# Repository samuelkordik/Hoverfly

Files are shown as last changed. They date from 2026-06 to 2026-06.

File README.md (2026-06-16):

# Hoverfly
"Hoverfly" was the nickname given by the RAF to the Sikorsky R-4, the first military helicopter to enter service for Allied forces (during WWII). So it's the name I'm giving to my first 3D printer.

The printer is a Creality Ender 3 Pro with the following modifications/additions:

- SKR Mini E3 V2.0 mainboard
- Dual Z-axis — two steppers + lead screws, parallel-wired to the single Z driver
- Sprite Extruder Pro direct-drive extruder + hotend
- Dual 24 V 5015 blower parts cooling on a printed Taurus V5 duct
- CRTouch probe
- Marlin firmware

This repository is for me to keep track of configuration and firmware files.

## Documentation

- **[Firmware review](docs/firmware-review/index.html)** ([markdown](docs/firmware-review/firmware-review.md)) — prioritized Marlin config recommendations.
- **[Orca Slicer guide](Orca_Slicer/index.html)** ([markdown](Orca_Slicer/orca-slicer-guide.md)) — Elegoo PLA, with Speed and Quality profiles.
- **[Calibration & tuning guide](Calibration_Guide/index.html)** — 9-step ordered tune-up with [STL test models](Calibration_Guide/STL/) and ready-to-run [SD macro files](Calibration_Guide/macros/) (no G-code terminal needed — everything runs via the LCD, Orca's calibration tests, or printing a macro from SD); also a structured [GUIDE.md](Calibration_Guide/GUIDE.md) and a [CLAUDE.md](Calibration_Guide/CLAUDE.md) for working through calibration interactively with Claude.

### How these were built

These guides were produced by a multi-agent research workflow: parallel agents did real web research
(Marlin docs, Ellis' Print Tuning Guide, Teaching Tech, RepRap wiki, and vendor/community sources)
grounded in Hoverfly's actual firmware values, then wrote the guides, the 9-step procedure, and the
calibration test STLs. The raw structured findings behind every recommendation — including seven that
were recovered from the agent transcripts after the run was interrupted partway — are preserved in
[`docs/research/`](docs/research/README.md). The firmware review changes no firmware files; it's advisory,
and motion/temperature numbers should be confirmed against the calibration guide before you commit them.

## Hardware mods (current + planned)

**Current**

- **Dual Z** — two Z steppers + lead screws on the Creality kit's **parallel** Y-splitter, off the single
  Z driver (the board has no spare). Firmware is correctly single-Z. Works as-is; if Z ever lacks torque,
  raise the Z driver current, or switch to a series splitter cable.
  See [firmware review §1](docs/firmware-review/index.html#dualz).
- **Parts cooling** — the stock fan died; replaced with **dual 24 V 5015 blowers** on a printed
  **Taurus V5 duct (PLA)**, spliced to the Sprite Extruder Pro's part-fan connector (driven by the
  mainboard's FAN0). Firmware: add `FAN_KICKSTART_TIME` / `FAN_MIN_PWM` so they start at low PWM.
  See [firmware review: fan wiring](docs/firmware-review/index.html#fans). (The PLA duct sits near the
  hotend — reprint in PETG/ABS if it sags.)

**Planned**

- **12 V buck converter** off the PSU → barrel-jack receiver, to run a 12 V fan that circulates the
  **heated bed's warmth for drying filament**.
- **5 V buck converter** off the PSU → USB-A port, for a **removable** USB LED light bar (kept unwired so
  it can come off for other uses).
- **Klipper migration** — host on a wiped x86 ThinkPad, reflash the SKR Mini E3 V2.0; gains a web G-code
  console (which removes the current no-terminal limitation) and first-class input shaping. Marlin-now is
  the priority. See [firmware review: Future — Klipper](docs/firmware-review/index.html#klipper).

> The buck converters are PSU-side (no firmware impact). Size them to the PSU's spare wattage, fuse each
> output, and use appropriate wire gauge.

## Marlin Configuration Adjustments
Using the "Creality/Ender-3 Pro/BigTreeTech SKR Mini E3 2.0" config example, with the following key changes:

```c
#define DEFAULT_KP 21.73
#define DEFAULT_KI 1.54
#define DEFAULT_KD 76.55

#define DEFAULT_AXIS_STEPS_PER_UNIT { 80, 80, 400, 423 } // E calibrated for the Sprite Extruder Pro
#define EDITABLE_STEPS_PER_UNIT                           // Allow tuning steps/mm from the LCD / via M92

//#define Z_MIN_PROBE_USES_Z_MIN_ENDSTOP_PIN      // Probe is connected to Z-probe slot on board, not Z endstop.
#define USE_PROBE_FOR_Z_HOMING                    // Force use of probe for Z-axis homing
#define BLTOUCH
#define NOZZLE_TO_PROBE_OFFSET {-30, -40, -3.49 } // Experimentally verified.
#define PROBING_MARGIN 50                         // Wanting to stay inside bed cleanly
#define XY_PROBE_FEEDRATE (50*60)                 // Not sure why
#define MULTIPLE_PROBING 2                        // Doing two readings (average of fast + slow) seems like a good idea.
#define Z_PROBE_OFFSET_RANGE_MIN -10
#define Z_PROBE_OFFSET_RANGE_MAX 10
#define X_BED_SIZE 210                            // To ensure probe is able to stay in bed; might adjust in future
#define Y_BED_SIZE 210

#define AUTO_BED_LEVELING_BILINEAR
//#define MESH_BED_LEVELING
#define RESTORE_LEVELING_AFTER_G28
#define PREHEAT_BEFORE_LEVELING                    // Of course, we want this—shouldn't this be the default?

#define Z_SAFE_HOMING
  #define Z_SAFE_HOMING_X_POINT ((X_BED_SIZE - 10) / 2)  // (mm) X point for Z homing
  #define Z_SAFE_HOMING_Y_POINT ((Y_BED_SIZE - 10) / 2) // (mm) Y point for Z homing

#define HOMING_FEEDRATE_MM_M { (50*60), (50*60), (4*60) }
```

And in Configuration_adv.h:

```c
//#define USE_CONTROLLER_FAN                      // Because the controller (mainboard) fan is wired to PWR instead of fan1

#define E0_AUTO_FAN_PIN FAN1_PIN                  // Hot-end fan is wired to FAN1 connector on board
```

## Changes Since Last Documented

These adjustments were made to the Marlin configuration *after* the table above
was first written and were not reflected in it. They are highlighted here so the
delta is easy to track.

### `Configuration.h`

- **Extruder steps/mm: `93` → `423`.** `DEFAULT_AXIS_STEPS_PER_UNIT` was bumped
  from the stock Ender-3 value to calibrate the **E axis** for the Sprite
  Extruder Pro direct drive. The X/Y/Z values (`80, 80, 400`) are unchanged.

  ```c
  -#define DEFAULT_AXIS_STEPS_PER_UNIT   { 80, 80, 400, 93 }
  +#define DEFAULT_AXIS_STEPS_PER_UNIT   { 80, 80, 400, 423 }
  ```

- **Added `EDITABLE_STEPS_PER_UNIT`.** Enables tuning steps/mm at runtime from
  the LCD or via `M92` (and storing it to EEPROM), which makes dialing in the
  new extruder calibration easier.

- **`NUM_M106_FANS` example changed `1` → `2`.** Still commented out, so this is
  a no-op functionally — noted only for completeness.

  ```c
  -//#define NUM_M106_FANS 1
  +//#define NUM_M106_FANS 2
  ```

### `Marlin/src/pins/stm32f1/pins_BTT_SKR_MINI_E3_V2_0.h`

- **Disabled the board-default controller-fan pin.** The `CONTROLLER_FAN_PIN`
  fallback to `FAN1_PIN` was commented out. This complements the disabled
  `USE_CONTROLLER_FAN` in `Configuration_adv.h` and keeps **FAN1** dedicated to
  the hot-end auto-fan (`E0_AUTO_FAN_PIN`), since the mainboard fan is wired to
  PWR rather than a fan header.

  ```c
  -#ifndef CONTROLLER_FAN_PIN
  -  #define CONTROLLER_FAN_PIN            FAN1_PIN
  -#endif
  +// #ifndef CONTROLLER_FAN_PIN
  +//   #define CONTROLLER_FAN_PIN            FAN1_PIN
  +// #endif
  ```

> Note: these changes currently exist as uncommitted edits in the `Firmware`
> submodule (working tree), so they are not yet captured in the submodule's git
> history.

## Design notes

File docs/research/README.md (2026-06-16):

# Recovered research payloads

Raw structured output from the multi-agent research workflow that produced the
[firmware review](../firmware-review/index.html), [Orca Slicer guide](../../Orca_Slicer/index.html),
and [calibration guide](../../Calibration_Guide/index.html). Kept here as the source data behind those
guides — the guides are the curated output; these are the unedited findings.

## Why these exist

The workflow ran **10 research agents** (each doing real WebSearch/WebFetch across Marlin docs, Ellis'
Print Tuning Guide, Teaching Tech, RepRap wiki, and vendor/community sources) before the build phase.
The session hit its limit mid-run: only **3** research results were captured and fed the build agents;
the other **7** finished their work but their results were lost when the orchestrator stopped. All 10
were later **recovered from the agent transcripts** and the genuinely-new findings folded back into the
guides (see [the firmware review changelog of findings](../firmware-review/firmware-review.md)).

| File | Topic | Recs | Into build? |
|---|---|-----:|:---:|
| [`firmware.json`](firmware.json) | Prioritized Marlin firmware review | 12 | recovered |
| [`orca.json`](orca.json) | Orca setup, Elegoo PLA, Speed + Quality profiles | 16 | recovered |
| [`cal-esteps-flow.json`](cal-esteps-flow.json) | E-steps / extrusion-multiplier (flow) | 6 | ✅ captured |
| [`cal-pid.json`](cal-pid.json) | Hotend PID autotune (M303) | summary | recovered |
| [`cal-zoffset-firstlayer.json`](cal-zoffset-firstlayer.json) | CRTouch Z-offset / first layer | summary | recovered |
| [`cal-temp-tower.json`](cal-temp-tower.json) | Temperature tower (Elegoo PLA) | 6 | ✅ captured |
| [`cal-retraction-pa.json`](cal-retraction-pa.json) | Retraction + pressure/linear advance | 7 | recovered |
| [`cal-speed-accel.json`](cal-speed-accel.json) | Max speed / acceleration / junction deviation | 7 | ✅ captured |
| [`cal-input-shaping.json`](cal-input-shaping.json) | Ringing / Input Shaping (M593) | 6 | recovered |
| [`cal-bed-mesh.json`](cal-bed-mesh.json) | Bed leveling / mesh (G29) | 6 | recovered |

## Schema

Each file is one research topic:

```jsonc
{
  "topic": "…",
  "summary": "concise overview of findings",
  "recommendations": [
    {
      "title": "…",
      "priority": "High | Medium | Low",
      "currentValue": "current config/slicer value or n/a",
      "recommendedValue": "…",
      "rationale": "why",
      "howToApply": "exact #define / M-code / slicer setting",
      "sources": ["https://…"]
    }
  ],
  "procedure": "step-by-step test + pass/fail (calibration topics only)",
  "imageNeeds": ["…"],
  "stlModel": "test model used, or empty"
}
```

> These are **point-in-time** web-research artifacts (gathered mid-2026). Treat the guides as the
> reviewed, deduplicated version; consult these for the full rationale and source URLs behind a
> recommendation. `cal-pid` and `cal-zoffset-firstlayer` are summary-only (no structured
> recommendations array) — that's how they were returned.

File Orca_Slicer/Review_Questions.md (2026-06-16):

# Orca Slicer Guide — Review Questions & Notes

My read-through of [`orca-slicer-guide.md`](orca-slicer-guide.md) / [`index.html`](index.html) before I
build the printer profile. Comfortable with the config logic; new to slicer conventions.

## Questions

1. **Bed 210 vs the 220 plate — RESOLVED: keep 210.** The guide sets the Orca bed to **210 × 210** to
   match firmware (`X/Y_BED_SIZE 210`), accepting a ~10 mm dead border on the physical 220 plate. The
   `Ender 3 S1 Pro buildplate 220x220.stl` and `Grid Texture 220x220.png` in the repo root are **not**
   the target — treat them as unused/cosmetic, don't wire them into the Orca bed model (a 220 texture
   under a 210 bed shape would mismatch). No guide change needed. *(Decision confirmed 2026-06-16.)*

2. **Does Orca's jerk setting do anything here?** §2 lists "Jerk X/Y ~8 (advisory)" and notes classic
   jerk is **off** (firmware uses Junction Deviation 0.08). If firmware ignores jerk in favor of JD,
   then the Orca jerk field is cosmetic, right? If so, say "leave default / ignored" so I don't waste
   time tuning a number that has no effect. If it *does* get emitted as `M205 J`/`M566`, clarify.

3. **Temperature numbers don't quite agree across sections.** The filament table (§3) says nozzle
   **200–210 °C** (first layer +5). The Speed profile (§4) says **210–215**, Quality says **200–205**.
   I assume the intent is "Speed runs hotter for throughput, Quality cooler for detail, all within the
   200–215 envelope," but as written the §3 ceiling (210) is below the §4 Speed value (215). Is 215 OK
   for this Elegoo PLA, or should Speed cap at 210? The temp tower (Cal §5) presumably settles this, but
   I want the starting profile to not contradict itself.

4. **Max volumetric speed ~11 mm³/s — where does that come from and how do I verify it?** §3 lists it
   and §6 names a "Max volumetric speed" calibration as the last step, but there's no STL or macro for
   it in the Calibration guide's step list (Cal has no dedicated MVS step). Is the plan to use Orca's
   built-in MVS test? If so, a pointer would help; right now 11 reads as an unverified default.

5. **Start G-code `M420 S1 Z10` with no stored mesh.** §5 says start G-code loads a *stored* mesh
   instead of probing each print. What happens on the very first print, or after an EEPROM reset, when
   no mesh is stored yet — does it silently print with no compensation (possible nozzle crash / bad
   first layer)? Should the start G-code guard for "mesh valid" or should I just run `G29`+`M500`
   (Cal §9) **before** ever using this start block? Spelling out the prerequisite would prevent a
   first-print faceplant.

6. **First layer height 0.28 mm on the Speed profile.** That's 70% of a 0.4 nozzle for the *first*
   layer. Is that intentional for draft speed, and is bed adhesion still reliable at 0.28 first layer,
   or should first layer stay ≤0.24 even in Speed? New-to-printing question — I don't have intuition for
   how aggressive a first layer can be.

## Confusing

7. **"Pressure advance OFF if using Marlin K."** Clear in principle (pick one). Confirming the
   mechanics: in Orca I literally set Pressure Advance to disabled/0 in the filament profile, and rely
   on the firmware `M900 K` value. If I instead tune PA in Orca, I must make sure firmware
   `ADVANCE_K`/`M900 K` is **0**. Both guides say "pick one" — I just want to confirm there's no Orca
   toggle that silently re-emits `M900` and double-applies.

8. **Machine max accel 500 in Orca vs print accel 1500–2000 in the Speed profile.** §2 mirrors firmware
   max accel at 500, but the Speed profile (§4) lists print accel 1500–2000 "(needs firmware)." So out
   of the box, Orca will clamp my 1500 print accel down to the 500 machine-limit until I raise the
   firmware ceiling (Cal §7) **and** the Orca machine-limit. Two places to change, in order. Worth a
   one-liner that the Orca machine limit also has to be raised, not just firmware.

## Notes to self

- The retraction-speed clamp (25 mm/s firmware E max feedrate) is called out here and matches the
  firmware review and Cal guide — tune retraction **distance**, not speed. Consistent. Good.
- Direct-drive short retraction (0.6–0.8 mm) — don't carry over any Bowden-sized numbers.
- Per-profile detail lives in `profiles/SPEED.md`, `profiles/QUALITY.md`, `profiles/printer-settings.md`
  — read those before locking presets.
- Action: build the printer profile at firmware-true limits first (210 bed, 500 accel), get a clean
  first layer, *then* raise accel after Cal §7. Don't start from the aspirational Speed numbers.
</content>

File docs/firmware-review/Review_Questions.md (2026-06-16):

# Firmware Review — Review Questions & Notes

My read-through of [`firmware-review.md`](firmware-review.md) / [`index.html`](index.html) as the
person who'll actually flash this board. I'm comfortable with the firmware/electronics side but new to
3D-printing-specific conventions, so my questions skew toward "does this match what's *actually* in the
config" and "how do I do this with no serial console."

## Things to verify against the real config (highest value)

1. **S-curve vs Linear Advance — does the current firmware even build?** §2/§8 say
   `S_CURVE_ACCELERATION` and `LIN_ADVANCE` are *both* enabled, and that Marlin's sanity check
   `#error`s on that pair unless `EXPERIMENTAL_SCURVE` is forced. But this firmware is presumably
   compiling and running today. So one of three things is true and I want to know which **before** I
   touch anything:
   - `S_CURVE_ACCELERATION` isn't actually enabled (then there's nothing to fix), or
   - `EXPERIMENTAL_SCURVE` is defined (masking the error), or
   - `LIN_ADVANCE` isn't actually compiled in.
   **Action:** grep `Configuration_adv.h` for all three before writing the §2b fix. The recommendation
   is sound, but the premise should be confirmed, not assumed.

2. **`LEVELING_BED_TEMP` — is it even defined?** §6 and Cal §9 both say "check it, set it to 60."
   Is this currently set, unset (defaulting to what?), or commented out in our config? A one-line grep
   answers it and turns "check this" into a concrete edit.

3. **`PROBING_MARGIN 25` with a 40 mm probe Y-offset.** §5 wants margin dropped 50→25, but the probe
   sits 30 mm left / **40 mm front** of the nozzle. With a 25 mm margin, does the probe physically clear
   the bed at the front-row points, or does Marlin shift them inward automatically? I'd like the *math*
   for the smallest safe margin given a {-30,-40} offset, rather than "lower it and watch G29, raise if
   it deploys off the bed." Trial-and-error off a hot bed is the thing I most want to avoid.

## No-terminal gaps (the workflow says "no G-code console")

4. **How do I raise the Z driver current without a serial console?** §1 says if dual-Z parallel lacks
   torque, raise `Z UART_CURRENT_MA` to ~800–1000 mA. Is that a `#define` (reflash) or a live `M906 Z…`
   + `M500`? If it's `M906`, there's **no SD macro for it** in `macros/` — the others (PID, esteps, PA,
   shaper, accel, zoffset, mesh) all have one. Should we add a `SET_ZCURRENT.gcode`? And what's the
   stock Z current we'd be raising *from*?

5. **Bed PID** (§4) — `PID_BED.gcode` exists, good. But confirming the path: `PIDTEMPBED` is a compile
   flag (reflash), *then* the macro autotunes. The guide is clear, just confirming I read the
   two-step (reflash → macro) correctly.

## Confusing / possibly inconsistent

6. **F103 RAM figure contradicts itself.** §7 says the STM32F103 has "**20 KB RAM**," but the "Making
   it fit" paragraph and the code comment both say "**48 KB SRAM**." The SKR Mini E3 V2.0's part is the
   STM32F103RC (48 KB). The "20 KB" looks like a stray wrong number — worth fixing so the Input Shaping
   feasibility call is based on the right budget.

7. **`FAN_MIN_PWM 75` vs the slicer's "0% on layer 1."** §Fans adds `FAN_MIN_PWM 75` (~30% floor) so
   the 5015s don't stall, and the Orca profiles run the part fan at 0% for layer 1. Does `FAN_MIN_PWM`
   force the fan to 30% even when the slicer commands 0 — i.e. will my first layer always have airflow?
   My understanding is the floor only applies to *non-zero* commands (0 = off), but I'd like that stated
   explicitly, because layer-1 cooling actively hurts PLA bed adhesion.

8. **`FAN_KICKSTART_TIME 150` / `FAN_MIN_PWM 75` units.** Confirm `75` is out of 255 (≈29%), not a
   percent, and `150` is ms. The comments imply it but I want to be sure before I trust the floor value.

9. **Dual-Z current split, mechanically.** §1 says two motors "split" the one driver's current. For
   two steppers wired in **parallel**, the driver's set current is shared but not necessarily evenly
   (depends on each motor's back-EMF / position). Is the practical assumption "each sees ~half"? That
   affects how high I should push `UART_CURRENT_MA` before worrying about the ~1.4 A RMS driver ceiling.

## Notes to self

- The only firmware change actually committed is E-steps 93→423 (and it's currently an *uncommitted*
  working-tree edit in the submodule per the README). **Everything else in this review is a reflash I
  haven't done yet.** Plan: branch the submodule, do **one** toggle per build, flash, verify, `M500`.
- Priority order I'm taking from this: (1) §2b disable S_CURVE — but only after confirming item #1
  above; (2) §2 calibrate Linear Advance K via Cal §6; (3) §3 `BABYSTEP_ZPROBE_OFFSET` so my live
  Z-offset actually persists (this one bites in Cal Step 4 — see that guide's questions). Bed PID,
  probe margin, mesh density, Input Shaping are all "nice to have."
- `M48`, `M503`, `M420 V` are serial-only → deferred to the planned Klipper move. Accepted.
- The retraction-speed clamp (E max feedrate = 25 mm/s) shows up in all three guides consistently —
  good, no contradiction there.
</content>
</invoke>

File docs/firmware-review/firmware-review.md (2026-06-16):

# Hoverfly — Marlin Firmware Review

Prioritized configuration recommendations for the Creality Ender 3 Pro with SKR Mini E3 V2.0,
Sprite Extruder Pro (direct drive), CRTouch, and TMC2209 drivers.

> **Review only** — no firmware files were modified. Each item gives the current value, the
> recommendation, and how to apply it (`#define` edit and/or live `M`-code). Confirm motion/temp
> numbers against the [Calibration Guide](../../Calibration_Guide/GUIDE.md) before committing.

## Priority table

| # | Area | Current | Recommended | Priority |
|---|---|---|---|---|
| 1 | Dual-Z wiring | Two motors **parallel** on one Z driver (Creality cable); firmware single-Z (correct) | Works as-is; raise Z current if torque short; series = optional cable swap | LOW |
| 2 | Linear Advance | `LIN_ADVANCE` on, `ADVANCE_K 0.0` | Calibrate K (~0.02–0.10 for Sprite direct drive) | **HIGH** |
| 2b | S-curve × Lin. Advance | `S_CURVE_ACCELERATION` + `LIN_ADVANCE` both on (OK on Marlin 2.1.2.7) | Optional: try with S-curve off; not required — the pair is supported | LOW |
| 3 | Live Z-offset | `BABYSTEP_ZPROBE_OFFSET` off | Enable so babysteps adjust & save probe Z-offset | MED |
| 4 | Bed heating | bang-bang (`PIDTEMPBED` off) | Optional: bed PID + autotune | MED |
| 5 | Probe coverage | `PROBING_MARGIN 50` | Reduce to ~20–30 mm | MED |
| 6 | Mesh density | 4×4 grid | 5×5 | LOW |
| 7 | Input Shaping | disabled | Try Marlin IS; fall back to slicer/Klipper | MED |
| 8 | Motion / JD | accel 500, JD 0.08 | Keep; tune via calibration | LOW |
| 9 | QoL items | mostly off | Optional (see §9) | LOW |

## 1. Dual-Z wiring — parallel, one driver (LOW)

The "Dual Z-axis" mod is two Z steppers + lead screws driven from the **single** Z output via the
Creality kit's **parallel Y-splitter cable**. Firmware is correctly single-Z (`Z2_DRIVER_TYPE`
commented): the **SKR Mini E3 V2.0 has only 4 drivers (X, Y, Z, E0)** and no spare socket, so a second
*independent* Z driver isn't possible here. This works — the rest is optional.

- **Parallel current (watch this):** both motors share the one TMC2209, so they split its current. Stock
  Z current is **580 mA** (`Z_CURRENT`, `Configuration_adv.h`). If Z lacks torque or skips, raise it
  either by editing `Z_CURRENT` (reflash) or — since the TMC2209 is in UART mode — live via the new
  `SET_ZCURRENT.gcode` macro (`M906 Z<mA>` + `M500`, no reflash). The driver's *set* current is the
  **total** it sources for both motors; it divides ~50/50 on average but shifts with each motor's
  load/back-EMF, so budget against the **driver's ~1.4 A RMS ceiling** (total), not a per-motor figure.
  Keep the set value ≤ ~1000 mA and check the driver isn't hot. Z is slow, so this is rarely a problem.
- **Series is cleaner but a hardware swap:** series gives both motors full, synced current within the
  driver rating (Z's low speed makes the inductance penalty moot) — but the stock Creality cable is the
  **parallel** one, so series needs a *different* splitter cable. Optional, not urgent.
- **No auto gantry-align:** with one driver you **cannot** use `Z_STEPPER_AUTO_ALIGN` / `G34` — square
  the gantry manually (stays true even under future Klipper). Reword the README mod list to
  *"two Z motors, parallel-wired to the single driver."*

## Fan wiring & cooling — dual 5015 blowers

Three fans, two controllable 24 V PWM headers (FAN0/FAN1). The current wiring is already correct:

| Fan | Connect to | Firmware | Behaviour |
|-----|---|---|---|
| Hotend / heatbreak | **FAN1** | `E0_AUTO_FAN_PIN FAN1_PIN` | Auto-on when hot (`EXTRUDER_AUTO_FAN_TEMPERATURE 50`, speed 255) |
| Parts cooling — **dual 5015 blowers** | **FAN0** → Sprite PCB part-fan connector | default `M106` PWM | Slicer-controlled; two 5015s ≈ 0.2 A, within FAN0 |
| Mainboard / controller | **PWR** (always-on) | `USE_CONTROLLER_FAN` off | Hard-wired to power; correct as-is (not on a header) |

**One firmware add for the blowers** — they often won't start at low PWM:

```c
// Configuration_adv.h
#define FAN_KICKSTART_TIME 150   // (ms) full-speed pulse on start
#define FAN_MIN_PWM 75           // PWM floor out of 255 (~29%), not a percent — so they don't stall
```

**`FAN_MIN_PWM` only rescales non-zero speeds.** A commanded **0 is always fully off** (Marlin's own
comment: *"Value 0 always turns off the fan."*), so your layer-1 0% fan still means no airflow — PLA bed
adhesion is unaffected. The ~29% floor applies only when the slicer asks for a low but non-zero speed.

**PLA duct caveat:** the Taurus V5 duct is printed in PLA (softens ~60 °C) right by the hotend — watch for
sag on long/hot prints, reprint in PETG/ABS/ASA if it deforms. Keep the layer-1 fan low for adhesion; the
Orca profiles already ramp 0%→100% by layer 3.

## 2. Linear Advance K is 0.0 (HIGH)

`LIN_ADVANCE` is compiled in but `ADVANCE_K 0.0` = no effect. It pays off on a light direct drive
like the Sprite (crisper corners/seams, less bulging). Direct-drive PLA K is typically **0.02–0.10**.
Measure it (Orca "Pressure advance" test or Marlin K pattern — see Calibration Guide §6).

```gcode
M900 K0.04    ; set K (your measured value)
M500          ; save
M900          ; report
```
Or bake in: `#define ADVANCE_K 0.04` in `Configuration_adv.h`. **Pick one** of firmware K *or*
slicer pressure advance — not both.

> **S-curve + Linear Advance is fine on this Marlin (not a conflict).** Both `S_CURVE_ACCELERATION`
> (`Configuration.h`) and `LIN_ADVANCE` are enabled, and on **Marlin 2.1.2.7 that is supported** — the
> old sanity-check `#error` that rejected the pair was removed. Current Marlin guards the LA/S-curve
> math with `#if ANY(S_CURVE_ACCELERATION, LIN_ADVANCE)` (`planner.cpp`, `planner.h`) and compiles both
> together. No `EXPERIMENTAL_SCURVE` is needed — in fact defining it now *breaks* the build
> (`inc/Changes.h`: "EXPERIMENTAL_SCURVE is no longer needed and should be removed"), and it is not set
> here. **Your build is not secretly broken.** *Optional preference:* some find Linear Advance pressure
> timing crispest with S-curve off, since junction deviation already smooths corners, so you *may*
> `//#define S_CURVE_ACCELERATION` — but it is not required. Refs (historical, now resolved): Marlin
> [#22547](https://github.com/MarlinFirmware/Marlin/issues/22547),
> [#14728](https://github.com/MarlinFirmware/Marlin/issues/14728).

## 3. Enable BABYSTEP_ZPROBE_OFFSET (MED)

Babystepping is on, but `BABYSTEP_ZPROBE_OFFSET` is off. Enabling it makes live Z babysteps adjust
the **probe Z-offset**, so you dial the first layer by feel and `M500` to persist — ideal with a
CRTouch.

```c
// Configuration_adv.h
#define BABYSTEP_ZPROBE_OFFSET
```

## 4. Bed PID vs bang-bang (MED)

`PIDTEMPBED` disabled → bang-bang. Fine for PLA. Enable only for tighter bed-temp stability, and
**autotune** rather than trusting fallback constants:

```c
#define PIDTEMPBED        // Configuration.h, then rebuild
```
```gcode
M303 E-1 S60 C8 U1   ; bed autotune, 60C, 8 cycles, apply
M500
```
Recommendation: keep bang-bang for now.

## 5. PROBING_MARGIN 50 mm is large (MED)

With a 210 mm bed, margin 50 means the mesh only samples the central ~110×110 mm. Lower it to mesh
more of the bed:

```c
#define PROBING_MARGIN 25   // was 50
```
Marlin auto-clamps the probe grid so the pin always stays on the bed — no trial-and-error off a hot bed
needed. With offset `{-30,-40}` and `PROBING_MARGIN 25`, `probe.h`'s `_min/_max` bounds work out to
sampled region **X ∈ [25, 180], Y ∈ [25, 170]** (e.g. `max_x = MIN(210−25, 210−30) = 180`,
`max_y = MIN(210−25, 210−40) = 170`). The far edges are pulled in by the **offset**, not the margin; the
margin only governs how close to the front/left near edges the pin lands. The probe never deploys off the
bed at 25 (it stays on even down to ~10), so 25 is a conservative, verified-safe choice.

## 6. Mesh density 4×4 → 5×5 (LOW)

```c
#define GRID_MAX_POINTS_X 5   // Y inherits
```

**Probe at print temperature.** `PREHEAT_BEFORE_LEVELING` is on, but `LEVELING_BED_TEMP` is currently
**`50`** (`Configuration.h`) — below your ~60 °C PLA bed, so the mesh is probed ~10 °C cold, and aluminum
warps differently when hot, so a cold mesh misses real warp. Set `#define LEVELING_BED_TEMP 60` (reflash),
or probe fresh in start G-code after a soak (`M190 S60` → `G4 S300` → `G28` → `G29` → `M500`). An `M48 P10` probe-repeatability
check (target σ < 0.02 mm) is worthwhile too, but it only reports over serial — it waits for the Klipper
console. See Calibration Guide §9.

## 7. Input Shaping on STM32F103 (MED)

`INPUT_SHAPING_X/Y` disabled. IS cancels ringing and enables higher accel, but the SKR Mini E3 V2.0
is an STM32F103RC (72 MHz, **48 KB** SRAM) — the build may still overflow because Marlin IS is
RAM-hungry, or limit step rate.

- **Try:** enable both, set frequencies from a ringing-tower measurement, live-tune `M593 X F.. ` /
  `M593 Y F..`, then `M500`.
- **If it won't fit:** drop it; keep accel modest, or move to Klipper for first-class input shaping.

```c
#define INPUT_SHAPING_X
#define INPUT_SHAPING_Y
#define SHAPING_MIN_FREQ 20.0   // caps the SRAM step buffer so it fits on 48KB F103
```

**Making it fit (48 KB SRAM).** The IS step buffer grows with steps/mm and feedrate; `SHAPING_MIN_FREQ
20.0` bounds it. After enabling, **build and read the linker summary before flashing** — if it says
*"region RAM overflowed"*, free SRAM (drop unused LCD languages, keep `SHAPING_MENU` off) or skip IS.
**Tuning order:** measure frequency → `M593 X F.. Y F..`, then damping `M593 X D.. Y D..` (zeta ~0.15,
step 0.05). **Re-tune Linear Advance K *after* IS** (the sweep runs with LA off): mechanics → IS → LA K.

## 8. Motion limits / junction deviation (LOW)

- `DEFAULT_ACCELERATION 500` — conservative; the Sprite is light, you can likely reach 1000–2000
  after a ringing test.
- `JUNCTION_DEVIATION_MM 0.08` — good default. Lower 0.05 = crisper/slower, higher 0.10–0.13 =
  faster/rounder.
- `S_CURVE_ACCELERATION` on — fine alongside `LIN_ADVANCE` on this Marlin (2.1.2.7); disabling it is an
  optional preference, not a fix (see §2). Z feedrate 5 mm/s and E max accel 5000 are fine.

Raise limits only with a test; firmware ceiling must be ≥ slicer requests.

> **Gotcha — E max feedrate caps retraction speed.** `DEFAULT_MAX_FEEDRATE` E is **25 mm/s**, so any
> slicer retraction speed above 25 is silently clamped. The "40 mm/s" retraction in the slicer/calibration
> guides never actually happens — either set slicer retraction speed to **≤ 25 mm/s**, or raise the E
> ceiling (`M203 E50` + `M500`) if you want faster retracts. A light Sprite rarely needs more than ~25.

## 9. Smaller items / QoL (LOW)

- `ALLOW_LOW_EJERK` — `DEFAULT_EJERK` is `5.0` with `LIN_ADVANCE` on. With `CLASSIC_JERK` off you're on
  junction deviation, so Marlin's `DEFAULT_EJERK >= 10` check is **compiled out entirely** (`SanityCheck.h`
  guards it with `NONE(HAS_JUNCTION_DEVIATION, ALLOW_LOW_EJERK)`). So `DEFAULT_EJERK 5.0` is harmless and
  `ALLOW_LOW_EJERK` is **not needed** here — it would only matter if you switched back to classic jerk.
- `G26_MESH_VALIDATION` — commented out; enable to print a single-layer pattern (`G26`) that confirms
  the mesh gives a flat first layer across the whole bed (companion to `M48` repeatability).
- `PROBING_HEATERS_OFF` — enable if probing is electrically noisy.
- `POWER_LOSS_RECOVERY` — off; enable only if you need it (adds SD writes).
- Sensorless homing — not worth it (physical endstops present, DIAG jumpers needed).
- `TEMP_SENSOR_0 = 1` — confirm if temps read oddly.
- `EDITABLE_STEPS_PER_UNIT` — already on (good).
- `THERMAL_PROTECTION_CHAMBER` — enabled w/o chamber heater; harmless.

## Applying & saving

| Path | Use for | Steps |
|---|---|---|
| Value change (no terminal) | K-factor, PID, steps/mm, mesh, Z-offset, accel, shaper freq | No G-code console — use an LCD-menu action, an Orca calibration test, or an SD macro (`../../Calibration_Guide/macros/`); each saves with `M500`. `M48`/`M503`/`M420 V` are serial-only (skip; defer to Klipper) |
| Recompile | feature toggles (`BABYSTEP_ZPROBE_OFFSET`, `PIDTEMPBED`, `INPUT_SHAPING_*`, `GRID_MAX_POINTS`, `PROBING_MARGIN`) | edit `Configuration*.h` → build (PlatformIO) → flash `firmware.bin` via SD → recalibrate → `M500` |

Change **one** thing at a time, reflash, verify, `M500`. Keep firmware edits on a branch.

## Future: Klipper migration (planned)

Longer-term: host **Klipper on a wiped x86 ThinkPad** (a laptop host is fully supported — no Pi needed)
and reflash the SKR Mini E3 V2.0 as the Klipper MCU (a reference board). **Marlin-now is the priority**;
this is a separate project. Two big wins here:

- **Solves the no-terminal problem** — Mainsail/Fluidd give a web G-code console, so the serial-only
  blockers (`M48`, `M503`, mesh dumps) and PID/shaper tuning all become live.
- **Input Shaping is native** and not RAM-constrained like Marlin IS on the F103 (§7).

Carry-over vs. redo:

| Setting | Marlin | Klipper | Carry over? |
|---|---|---|---|
| Steps/mm | `M92` | `rotation_distance` | Recompute |
| Pressure advance | `M900 K` | `pressure_advance` | Re-tune |
| Hotend/bed PID | `M303` | `PID_CALIBRATE` | Re-tune |
| Bed mesh | `G29` | `BED_MESH_CALIBRATE` | Re-run |
| Input shaping | limited on F103 | native | Tune fresh (better) |
| Dual Z | one driver | one driver (no spare) | Still parallel/series on one driver (§1) |

## Sources

- Marlin docs — Linear Advance, Input Shaping, PID, Bed Leveling: <https://marlinfw.org/docs/>
- M900 / M593 G-code: <https://marlinfw.org/docs/gcode/M900.html>, <https://marlinfw.org/docs/gcode/M593.html>
- BTT SKR Mini E3 V2.0 hardware: <https://github.com/bigtreetech/BIGTREETECH-SKR-mini-E3>
- Teaching Tech calibration: <https://teachingtechyt.github.io/calibration.html>
- Ellis' Print Tuning Guide: <https://ellis3dp.com/Print-Tuning-Guide/>
- Marlin S-curve × Linear Advance — historical (now-resolved) incompatibility: issues [#22547](https://github.com/MarlinFirmware/Marlin/issues/22547), [#14728](https://github.com/MarlinFirmware/Marlin/issues/14728)
- Input Shaping on STM32F103 / SRAM limits: Marlin [#26183](https://github.com/MarlinFirmware/Marlin/issues/26183); `ALLOW_LOW_EJERK` PR [#23054](https://github.com/MarlinFirmware/Marlin/pull/23054)

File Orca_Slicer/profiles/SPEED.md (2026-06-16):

# ⚡ Speed / fast process profile — Elegoo PLA

For drafts, jigs, and big simple parts. Trades surface finish and fine detail for throughput.

> **Prerequisite:** raise firmware acceleration (Cal §7) to ~1500–2000 mm/s² **and** raise Orca's
> machine max-accel limit to match (two separate places — firmware first via `SET_ACCEL.gcode`/LCD,
> then the Orca machine limit) — otherwise the printer can't reach these speeds and the profile is pointless.

## Quality
- Layer height: **0.28 mm** · first layer: 0.28 mm (use 0.24 mm if first-layer adhesion is marginal — thick first layers are less forgiving on a cold/uneven bed)
- Line width: 0.45–0.50 mm (≥ nozzle for fatter, faster lines)
- Walls: **2** · top/bottom: 3 / 3
- Infill: **10–15%** grid (fast pattern)

## Speeds (mm/s)
- Outer wall: **120–150** (keep below inner — it's the visible surface)
- Inner wall: **200–250**
- Infill: **250–300**
- Top surface: 120 · Travel: **250**
- First layer: 25–30 (don't rush adhesion)

## Acceleration
- Print/travel: **1500–2000 mm/s²** (firmware ceiling must allow it)

## Temperature / flow
- Nozzle: **210–215 °C** (hotter to keep up with flow) · Bed: 60/55 °C
- Max volumetric speed: ~11 mm³/s starting default — verify with Orca's MVS test (guide §6); Orca will slow moves to respect whatever you set

## Retraction / PA
- Retraction: **0.8 mm @ 25 mm/s** (speed capped by firmware E feedrate 25 mm/s — tune distance, not speed)
- Pressure advance / Marlin K: keep tuned value; speed prints benefit most from correct PA

## Other
- Slow down for overhangs: **off** · Slow down for layer cooling: on (min layer time ~5 s)
- Seam: Nearest/Aligned · Supports: only if needed

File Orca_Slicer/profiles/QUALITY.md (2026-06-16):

# ◆ Quality / high-detail process profile — Elegoo PLA

For miniatures, mechanical fits, and display parts. Trades time for surface finish and fine features.

## Quality
- Layer height: **0.12–0.16 mm** · first layer: 0.20 mm
- Line width: **0.40 mm** (= nozzle, for crisp detail)
- Walls: **3–4** · top/bottom: 5 / 4
- Infill: **15–20%** gyroid (isotropic, clean top surfaces)

## Speeds (mm/s)
- Outer wall: **30–40** (slow = smooth) · Inner wall: **60**
- Infill: **80** · Top surface: 30 · Travel: 180
- First layer: 20–25 · Small-perimeter speed: 25 (slow tiny loops)

## Acceleration
- Print: **500 mm/s²** (firmware default is fine here — low accel helps detail)

## Temperature / flow
- Nozzle: **200–205 °C** (cooler = crisper, less stringing) · Bed: 60/55 °C
- Flow ratio: dialed from flow test; accuracy matters more at fine layers

## Retraction / PA
- Retraction: **0.6–0.8 mm @ 25 mm/s** (speed capped by firmware E feedrate 25 mm/s — tune distance, not speed)
- Pressure advance / Marlin K: tuned value — most visible on fine detail and seams

## Cooling / overhangs
- Fan: 0% layer 1 → **100%** by layer 3 · Min layer time: 8–10 s
- Slow down for overhangs: **on** · Slow down for layer cooling: on

## Other
- Seam: Aligned (or Back) for hidden seams · Ironing: optional on flat tops
- Supports: tree/normal as needed; support interface gap 0.2 mm

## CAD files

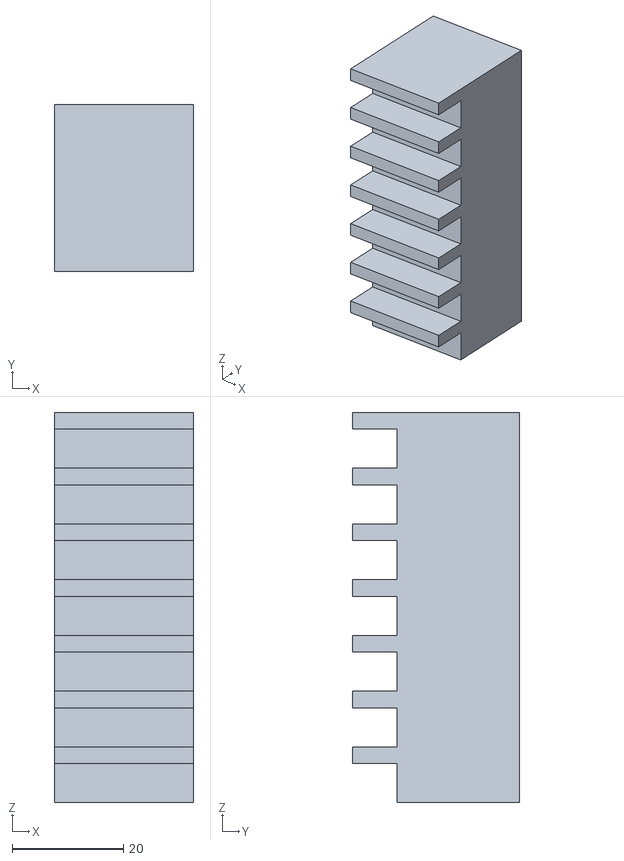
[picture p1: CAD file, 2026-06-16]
Calibration_Guide/STL/temp_tower_70mm.stl
25.0 x 30.0 x 70.0

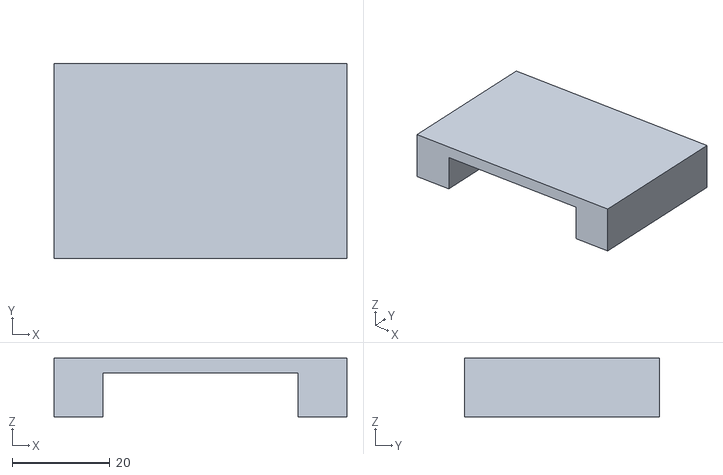
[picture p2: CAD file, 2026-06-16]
Calibration_Guide/STL/bridge_test_40mm.stl
60.0 x 40.0 x 12.0

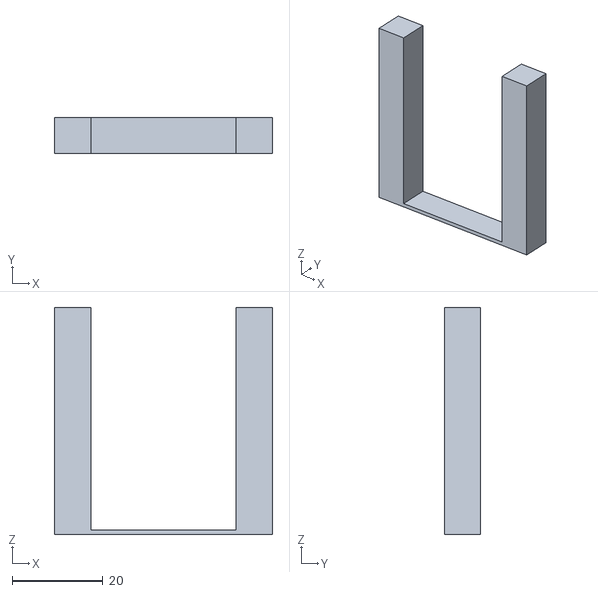
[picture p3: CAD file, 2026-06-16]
Calibration_Guide/STL/retraction_test_50mm.stl
48.0 x 8.00 x 50.0

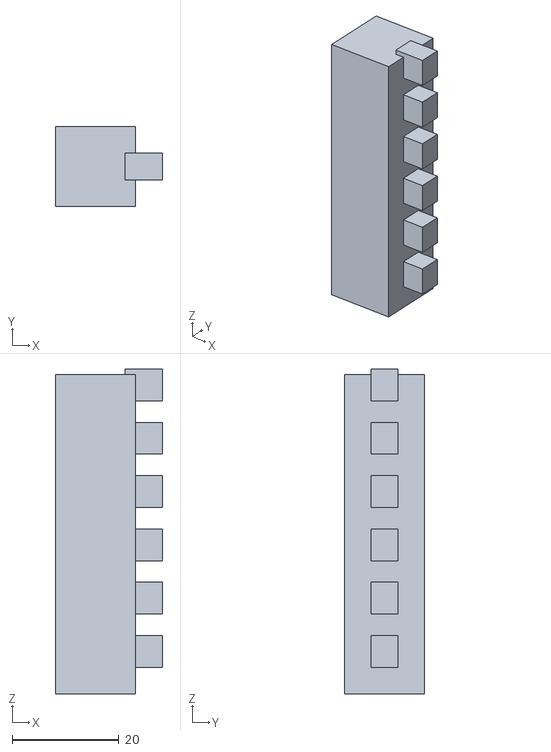
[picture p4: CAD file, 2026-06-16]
Calibration_Guide/STL/ringing_tower_60mm.stl
20.0 x 15.0 x 61.0

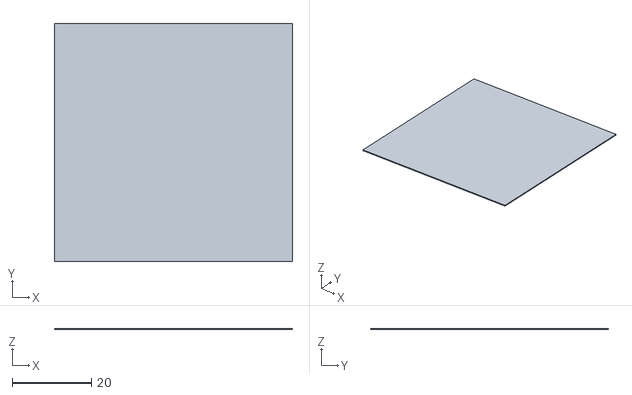
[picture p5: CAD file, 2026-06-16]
Calibration_Guide/STL/firstlayer_patch_60mm.stl
60.0 x 60.0 x 0.3

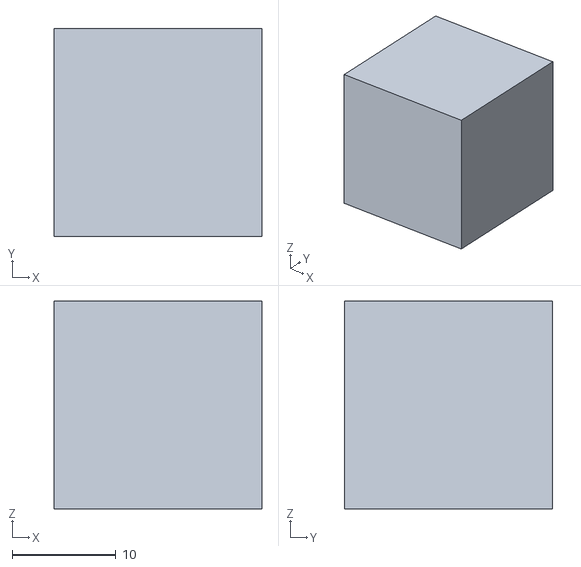
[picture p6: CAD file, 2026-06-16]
Calibration_Guide/STL/calibration_cube_20mm.stl
20.0 x 20.0 x 20.0

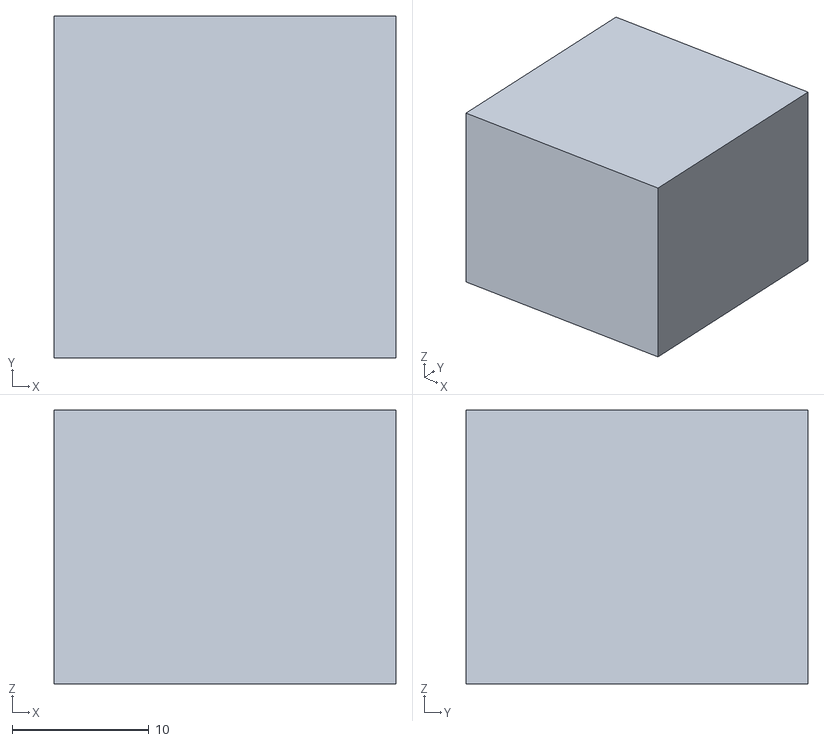
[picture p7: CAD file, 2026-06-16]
Calibration_Guide/STL/single_wall_flow_25mm.stl
25.0 x 25.0 x 20.0

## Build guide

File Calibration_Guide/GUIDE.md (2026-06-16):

# Hoverfly Calibration & Tuning Guide (structured)

Machine-parseable procedure for calibrating the Hoverfly (Ender 3 Pro · SKR Mini E3 V2.0 ·
Sprite Extruder Pro direct drive · CRTouch · TMC2209). Human-friendly version:
[`index.html`](index.html). Interactive driver: [`CLAUDE.md`](CLAUDE.md).

Each step has a stable `id` and the fields: **Goal**, **STL**, **Run** (how to do it with no G-code
terminal), **Setup**, **Commands** (the raw codes, for reference), **Observe**, **Pass criteria**,
**If fail**. Do the steps **in order** — later steps assume earlier ones passed.

## Firmware baseline (ground truth)

- Steps/mm `{80, 80, 400, 423}` (E already calibrated for Sprite). `EDITABLE_STEPS_PER_UNIT` on.
- Hotend PID `KP 21.73 / KI 1.54 / KD 76.55`. Bed = bang-bang (`PIDTEMPBED` off).
- `LIN_ADVANCE` on, `ADVANCE_K 0.0` (untuned). Input shaping off. `BABYSTEP_ZPROBE_OFFSET` off.
- ABL bilinear, 4×4 grid, `PROBING_MARGIN 50`, `NOZZLE_TO_PROBE_OFFSET {-30,-40,-3.49}`.
- Bed 210×210 (firmware), Zmax 250. Save with `M500` (built into the SD macros, or LCD → Store Settings).

Filament for all temp/flow numbers below: **Elegoo PLA** (≈190–220 °C hotend, 50–60 °C bed).

## Running these without a terminal

Hoverfly has **no G-code console** (no Pi / OctoPrint / USB terminal). Each step's **Run** line says how
to do it, one of three ways:

- **LCD menu** — steps/mm, acceleration, babystep Z, Store Settings (`M500`), and the mesh viewer.
- **Orca Slicer → Calibration menu** — generates the temperature / flow / pressure-advance / retraction
  tests as ordinary prints. No codes.
- **SD macro files** in [`macros/`](macros/) — for one-off commands (PID, mesh build, set-a-value). Copy
  them to the SD card once, then **Print** the named file. `SET_*` files must be **edited first**.

The **Commands** blocks below show the raw M-codes for reference (and for the planned Klipper console) —
you don't type them. `M48`, `M503`, and `M420 V` only report over USB serial, so they're skipped here:
use the **LCD mesh viewer**, and defer `M48` probe-repeatability to the Klipper move.

**First-run order (fresh printer):** the steps are written 1→9, but Step 4 (Z-offset) needs an active
mesh — a good first layer is mesh-compensated. So on a brand-new printer run **1 → 2 → 3 → 9 (build the
first mesh) → 4 → 5–8**. PID and E-steps (Steps 2–3) are independent and can precede the mesh; the mesh
itself (Step 9) builds fine before the Z-offset is dialed (it's relative). After that initial pass the
numeric 1→9 order is fine for re-tuning.

---

## Step 1: bed-tramming
- **Goal:** Mechanically level (tram) the bed so all four corners are within ~0.1 mm before relying
  on the CRTouch mesh. ABL compensates for small variation; it should not paper over a badly skewed bed.
- **STL:** none (use the LCD / live moves).
- **Run:** All on the **LCD**, no macro — heat the bed, Auto Home, then jog Z to ~0.2 mm and visit each
  corner (or use the Bed Tramming menu if your build has it).
- **Setup:** Heat bed to print temp (60 °C) so it sits at its working shape. Nozzle clean.
- **Commands:**
  ```gcode
  M140 S60      ; heat bed
  G28           ; home
  M211 S0       ; (reference only — disables soft endstops; re-enable with M211 S1 after)
  G1 Z0.2 F600  ; move nozzle near bed, then jog to each corner
  ```
  Use the paper-drag test at each corner knob; adjust knobs until drag is equal everywhere. The supported
  flow is **LCD jog only** — no macro sends `M211`, so soft endstops stay on. If you ever disable them
  manually (`M211 S0`), re-enable with `M211 S1` afterward (they also reset on power-cycle).
- **Observe:** Paper drag (slight resistance) feels identical at all four corners + center.
- **Pass criteria:** Corner-to-corner nozzle height varies by < 0.1 mm (paper drag consistent).
- **If fail:** Re-level corners; if one corner can't reach, check bed springs/silicone spacers and
  gantry squareness (both Z leadscrews at equal height — power off, hand-turn to match).

## Step 2: pid-hotend
- **Goal:** Confirm/refresh hotend PID so temperature holds ±0.5 °C at print temp.
- **STL:** none.
- **Run:** Print [`macros/PID_HOTEND.gcode`](macros/PID_HOTEND.gcode) from SD (autotunes with the part
  fan on, applies, and saves). `M303` pauses for an LCD acknowledge when it finishes — that's normal.
- **Setup:** The stored `KP/KI/KD` (21.73/1.54/76.55) are generic stock Ender-3 values, **not** autotuned
  for the Sprite Pro's heavier heater block — a fresh autotune is worthwhile. The macro tunes with the
  part fan on, matching real PLA printing.
- **Commands:** (what the macro runs — for reference, you don't type these)
  ```gcode
  M106 S255            ; part fan on (tune under print-like cooling)
  M303 E0 S205 C8 U1   ; autotune hotend at 205C, 8 cycles, apply result
  M107                 ; fan off
  M500                 ; save
  ```
- **Observe:** During a hold at 205 °C the temperature is stable, not sawtoothing > ±1 °C.
- **Pass criteria:** Steady-state within ±0.5–1 °C; no thermal-runaway trip.
- **If fail:** Re-run with more cycles (`C10`); check the hotend fan and that the thermistor/heater
  cartridge are seated. Existing values (21.73/1.54/76.55) are a fine fallback.

## Step 3: esteps-flow
- **Goal:** Verify extruder E-steps (already 423) and then dial slicer **flow / extrusion multiplier**.
- **STL:** [`STL/single_wall_flow_25mm.stl`](STL/single_wall_flow_25mm.stl)
- **Run:** E-steps — Print [`macros/ESTEPS_TEST.gcode`](macros/ESTEPS_TEST.gcode), measure, then set the
  new value via the **LCD Steps/mm** menu or [`macros/SET_ESTEPS.gcode`](macros/SET_ESTEPS.gcode) (edit
  first). Flow — use Orca's **Flow Rate** calibration (generates the print).
- **Setup (E-steps check):** Heat to 205 °C. Mark 120 mm of filament above the extruder. Measure the
  remaining filament **2–3 times (or re-run) and average** — a 1 mm read error is ~1% of E-steps. Mark
  and measure against a fixed point on the **extruder body**, not the nozzle tip. The test extrudes
  100 mm and does **not** retract, so expect a ~100 mm strand hanging from the nozzle — snip it off after
  measuring. **Confirm on LCD:** Configuration → Advanced Settings → Steps/mm → E steps/mm.
- **Commands (E-steps):**
  ```gcode
  M83            ; relative extrusion
  G1 E100 F60    ; extrude 100mm slowly
  ; measure remaining: 120 - (distance left) should equal 100mm extruded
  M92 E<new>     ; only if off: new = 423 * 100 / actual_extruded
  M500
  ```
- **Setup (flow):** Slice `single_wall_flow_25mm.stl` with **1 perimeter, 0 top/bottom layers,
  0% infill** (or Spiral/Vase mode), 0.2 mm layer. Print in Elegoo PLA.
- **Observe (flow):** Measure wall thickness with calipers at several spots (target = your line width,
  e.g. 0.42–0.45 mm for a 0.4 nozzle).
- **Pass criteria:** Walls within ±0.02–0.03 mm of target, consistent; no gaps between wall and itself.
- **If fail:** `new_flow = current_flow × (target_wall / measured_wall)`. Set flow ratio in Orca
  (Filament → Flow ratio) and reprint. Re-confirm E-steps if flow is wildly off (>10%).

## Step 4: zoffset
- **Goal:** Set CRTouch Z-offset for a perfect first layer; learn live babystepping.
- **STL:** [`STL/firstlayer_patch_60mm.stl`](STL/firstlayer_patch_60mm.stl)
- **Run:** **Until you reflash with `BABYSTEP_ZPROBE_OFFSET` (firmware review §3), use
  [`macros/SET_ZOFFSET.gcode`](macros/SET_ZOFFSET.gcode)** (edit `M851 Z<value>` + `M500`) — that
  persists. The **LCD live-babystep method** (double-click the encoder → **Babystep Z**, dial by feel) is
  great for finding the value, but with `BABYSTEP_ZPROBE_OFFSET` *off* the babystep is **not** folded into
  the probe offset by Store Settings and is lost on reboot; once that flag is enabled, the live method
  persists with **Configuration → Store Settings**. **Confirm on LCD:** Configuration → Probe Z Offset.
- **Setup:** Bed trammed (Step 1) **and a mesh already built (Step 9)** — on a fresh printer do Step 9
  before this step (see *First-run order* above). Nozzle + bed at PLA temps.
- **Commands:**
  ```gcode
  G28
  M851 Z-3.49        ; current probe Z-offset (info; from NOZZLE_TO_PROBE_OFFSET)
  ; start the firstlayer_patch print, then during layer 1:
  ;   double-click the encoder -> Babystep Z; nudge down (negative) if too high,
  ;   up (positive) if nozzle is dragging/scraping
  M500               ; save (note: persists Z babystep only if BABYSTEP_ZPROBE_OFFSET is enabled)
  ```
- **Observe:** First-layer lines squish together with no gaps, top surface smooth and matte-uniform,
  not translucent (too high) and not rough/ridged/scraped (too low).
- **Pass criteria:** Solid patch with no gaps between lines, no elephant-foot ooze, peels off in one piece.
- **If fail:** Adjust Z-offset ±0.02–0.05 mm and reprint a patch. See firmware review §3 — enabling
  `BABYSTEP_ZPROBE_OFFSET` makes the live babystep save into the probe offset with `M500`.

## Step 5: temp-tower
- **Goal:** Find the best nozzle temperature for this Elegoo PLA spool (adhesion vs stringing/quality).
- **STL:** [`STL/temp_tower_70mm.stl`](STL/temp_tower_70mm.stl) — 7 bands; sweep ~220 → 190 °C (one temp per band). For a fancier labeled tower see `STL/ATTRIBUTION.md`.
- **Run:** Orca → **Calibration → Temperature tower** generates the print and inserts the per-band temps
  for you — no codes. (Or slice the STL above with Orca's height-based temperature changes.)
- **Setup:** 0.2 mm layer, normal speed. Orca's temperature-tower calibration inserts `M104` per height.
- **Commands:** (Orca handles this; manual height-change marker shown for reference)
  ```gcode
  ; at each band height the slicer inserts e.g.:
  M104 S210
  ```
- **Observe:** Per band, judge layer adhesion (try to snap it), bridging strands, overhang quality,
  stringing, and surface finish.
- **Pass criteria:** Pick the **lowest** temperature that still gives strong layer bonding and clean
  surfaces — usually ~200–210 °C for Elegoo PLA.
- **If fail:** If every band strings, you're too hot and/or retraction needs Step 6; if layers
  delaminate at all bands, you're too cold or cooling too aggressively.
- **Loop back if needed:** Step 2 autotuned PID at 205 °C. If your chosen tower temp differs from 205 by
  more than ~10 °C, re-run [`macros/PID_HOTEND.gcode`](macros/PID_HOTEND.gcode) after editing it to
  autotune at your final temp (`M303 E0 S<temp>`), then `M500` — PID constants are mildly
  temperature-dependent, so tuning near your real print temp is best. A ±5–10 °C delta rarely matters.

## Step 6: retraction-pa
- **Goal:** Eliminate stringing/oozing (retraction) and sharpen corners/seams (pressure/linear advance).
- **STL:** [`STL/retraction_test_50mm.stl`](STL/retraction_test_50mm.stl) — two posts, travel across the 32 mm gap strings if retraction is poor; PA via Orca's calibration test.
- **Run:** Orca → **Calibration → Pressure Advance** (Pattern, Direct Drive) and **Retraction test** —
  both generate prints. Apply the chosen PA via Orca, or [`macros/SET_PA.gcode`](macros/SET_PA.gcode);
  set retraction distance/speed in Orca's filament/printer settings.
- **Setup:** Use the temp from Step 5. Direct drive = **short** retraction.
- **Commands / values:**
  ```gcode
  M83
  ; Orca Pressure Advance (Pattern, Direct Drive): sweep K 0.0–0.10 step 0.005, then a fine
  ; second pass at 0.002 around the best band. Or set Marlin Linear Advance directly:
  M900 K0.04     ; try a value
  M500
  ```
  **Order: tune pressure advance (K) first, then retraction** — good PA relieves nozzle pressure and
  shrinks the retraction you need. Retraction starting point (direct drive, Sprite): **0.6–0.8 mm @
  25 mm/s**. ⚠️ The firmware E max feedrate is **25 mm/s**, so any higher retraction speed is silently
  clamped — tune **distance**, not speed (or raise `DEFAULT_MAX_FEEDRATE` E). Tune distance down until
  stringing returns, then back up one notch. **Note:** Orca's *Enable pressure advance* checkbox injects
  `M900 K` into the print G-code and overrides firmware K every print, so **untick it** when you're relying
  on `SET_PA.gcode`/`M500` (Marlin K).
- **Observe:** Retraction tower — strings between towers. PA test — corner bulge / gaps at line ends.
- **Pass criteria:** No (or wispy, removable) strings; corners crisp with no bulge and no under-fill
  at the start of perimeters.
- **If fail:** More retraction **distance** for strings (speed is capped at 25 mm/s, so raising it does
  nothing; don't exceed ~1.5 mm on direct drive); adjust `M900 K` up if corners bulge, down if corners
  show gaps. Use **one** of Marlin K or Orca PA.

## Step 7: speed-accel
- **Goal:** Find the highest acceleration the machine runs without ringing/skips; raise firmware
  ceilings if needed.
- **STL:** [`STL/calibration_cube_20mm.stl`](STL/calibration_cube_20mm.stl) and/or [`STL/ringing_tower_60mm.stl`](STL/ringing_tower_60mm.stl).
- **Run:** Set acceleration via the **LCD Acceleration** menu or [`macros/SET_ACCEL.gcode`](macros/SET_ACCEL.gcode)
  (edit values first), then print the cube/tower from SD at each setting to test.
- **Setup:** Print the cube at increasing accel; watch for ghosting after sharp features and for
  skipped steps (layer shift).
- **Commands:**
  ```gcode
  M201 X1000 Y1000     ; raise max accel to test (firmware default 500)
  M204 P1000           ; print accel
  M203 X500 Y500       ; max feedrate (already high)
  M500                 ; save only the values you settle on
  ```
- **Observe:** Dimensional accuracy of the 20 mm cube (X/Y/Z within ±0.1–0.2 mm), echo/ghost lines
  after corners, any layer shift. **Confirm on LCD:** Configuration → Advanced Settings → Acceleration.
- **Pass criteria:** Cube measures 20 ±0.2 mm each axis; no skipped steps; acceptable ringing.
- **If fail:** Back off accel; if the cube is consistently off-dimension, recheck belt tension and
  steps/mm (X/Y 80, Z 400). Don't exceed what Step 8 shows is ring-free.

## Step 8: shaping
- **Goal:** Reduce ringing/ghosting — measure resonance and (optionally) enable Input Shaping.
- **STL:** [`STL/ringing_tower_60mm.stl`](STL/ringing_tower_60mm.stl) — nubs every 10 mm imprint resonance echoes.
- **Run:** Only if Input Shaping is compiled **and** fits. Sweep with the slicer "after layer change"
  macro (below), then apply the result with [`macros/SET_SHAPER.gcode`](macros/SET_SHAPER.gcode) (edit
  the measured frequencies first). If IS won't fit, this step is "lower accel" only (see *If fail*).
- **Setup:** **First confirm IS even fits on the F103.** Enable `INPUT_SHAPING_X/Y` plus
  `SHAPING_MIN_FREQ 20.0` (bounds the SRAM step buffer), build, and check the linker does **not** report
  *"region RAM overflowed"* before you bother printing (firmware review §7). Then print the ringing tower
  in vase mode at high accel (override the 500 ceiling for the test: `M204 S1500`) and sweep frequency up
  the tower with a slicer "after layer change" macro:
  ```gcode
  ; sweeps M593 frequency 15 → 60 Hz over the tower height:
  M593 F{(layer_num < 2 ? 0 : 15 + 45.0 * (layer_num - 2) / 297)}
  ```
- **Commands:** (only if IS compiled + fit) — read the smoothest band, convert its height to Hz, set per axis:
  ```gcode
  M593 X F40       ; X shaper frequency (from the cleanest band)
  M593 Y F38       ; Y shaper frequency
  M593 X D0.15 Y D0.15  ; damping (zeta) — then refine in 0.05 steps
  M500
  ```
  Then **re-tune Linear Advance K (Step 6) after IS** — the sweep runs with LA off, so K is finalized last.
- **Observe:** Ghosting echoes after sharp corners; their period gives the resonant frequency.
- **Pass criteria:** Visible reduction in ghosting; corners clean at your chosen accel.
- **If fail:** If IS won't build/flash, instead **lower acceleration** (Step 7) to the ring-free value.
  First-class resonance compensation is part of the planned Klipper migration (firmware review).

## Step 9: bed-mesh
- **Goal:** Produce a reliable ABL mesh and validate first-layer consistency across the whole bed.
- **STL:** [`STL/firstlayer_patch_60mm.stl`](STL/firstlayer_patch_60mm.stl) (print at several bed
  locations or scale up).
- **Run:** Print [`macros/BUILD_MESH.gcode`](macros/BUILD_MESH.gcode) from SD (heats, homes, probes,
  saves, enables). View the result on the **LCD mesh viewer** — `M420 V` and `M48` are serial-only, so
  skip `M48` probe-repeatability until the Klipper console.
- **Setup:** Probe at **real print temp**. `PREHEAT_BEFORE_LEVELING` is on, but `LEVELING_BED_TEMP` is
  currently **50** (below your 60 °C PLA bed), so a reflash to `#define LEVELING_BED_TEMP 60` is
  worthwhile; until then, run `G29` in start-gcode after the bed soaks (`M190 S60` → `G4 S300`). Clean
  nozzle (no ooze blob on tip). **Confirm on LCD:** Configuration → (Bed) Leveling → Mesh viewer.
- **Commands:** (what `BUILD_MESH.gcode` runs — for reference)
  ```gcode
  M140 S60 ; M104 S150   ; bed to print temp; warm nozzle (low ooze)
  M190 S60 ; M109 S150    ; wait for both
  G28
  G29                    ; probe the bilinear mesh
  M500                   ; store mesh
  M420 S1 Z10            ; enable leveling + fade height 10mm
  ; optional, separately: G26 B60 H205  (if G26_MESH_VALIDATION compiled) prints a mesh-check pattern
  ```
- **Observe:** View the stored mesh on the **LCD mesh viewer** — spread should be small (a few tenths).
  First-layer patches consistent in every region (optionally confirm with a `G26` pattern if compiled).
- **Pass criteria:** Mesh Z range < ~0.3–0.4 mm; first layer equally good center and edges.
- **If fail:** If the spread is large, redo Step 1 (tramming). Consider `GRID_MAX_POINTS 5×5` and
  lowering `PROBING_MARGIN` (firmware review §5–6) to mesh more of the bed.

---

## Done / save order

Each step that changes a stored value saves it with `M500` (the SD macros do this; or use the LCD →
Store Settings). Recommended end state: PID saved, flow dialed in Orca, Z-offset saved, best temp +
retraction + K saved, accel set, mesh stored and `M420 S1` enabled in your slicer's start G-code.
If the temp tower moved your print temp more than ~10 °C from 205, re-run hotend PID at the new temp.

> **Flash-emulated EEPROM caveat (SKR Mini E3 V2.0):** there's no real EEPROM — `M500` writes to a
> reserved flash sector and is reliable day-to-day, but a **reflash can change the EEPROM layout and
> reset all stored values to defaults**. After *any* firmware update, re-verify (and re-save) PID,
> E-steps, Z-offset, K, accel, and rebuild the mesh — don't assume they survived.

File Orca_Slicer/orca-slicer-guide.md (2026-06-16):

# Hoverfly — Orca Slicer Guide (Elegoo PLA)

Orca Slicer setup for the Ender 3 Pro · SKR Mini E3 V2.0 · Sprite Extruder Pro (direct drive) ·
CRTouch, printing **Elegoo PLA**. Human/HTML version: [`index.html`](index.html).

> Values are starting points tied to the firmware. Confirm flow / pressure advance / temperature /
> retraction in the [Calibration Guide](../Calibration_Guide/GUIDE.md), then lock them into the presets.

## 1. Add the printer (custom Marlin)

| Setting | Value | Why |
|---|---|---|
| Bed shape | 210 × 210 mm | Match firmware travel (`X/Y_BED_SIZE 210`). Plate is physically 220; firmware caps at 210. |
| Max height | 250 mm | `Z_MAX_POS 250` |
| Nozzle | 0.4 mm | standard |
| Flavor | Marlin | — |
| Extruder | Direct drive | Sprite Pro → short retraction, low PA |

## 2. Machine limits (mirror firmware)

| Limit | Value | Source |
|---|---|---|
| Max speed X/Y | 500/500 mm/s | `DEFAULT_MAX_FEEDRATE` |
| Max speed Z/E | 5/25 mm/s | `DEFAULT_MAX_FEEDRATE` |
| Max accel X/Y | 500/500 mm/s² | `DEFAULT_MAX_ACCELERATION` (raise via Cal §7) |
| Max accel E | 5000 mm/s² | `DEFAULT_MAX_ACCELERATION` |
| Jerk X/Y | leave default (no effect) | Classic jerk is OFF; firmware uses Junction Deviation 0.08, so Marlin **ignores** any `M205` X/Y jerk Orca emits. Only matters if you re-enable `CLASSIC_JERK`. (Marlin has no `M566`.) |

**Speed bottleneck:** firmware accel is 500 mm/s². Print accel is clamped by **both** the firmware
ceiling **and** Orca's machine max-accel limit (also 500). Raise them in order: (1) firmware via Cal §7
(`SET_ACCEL.gcode`/LCD + save), then (2) Orca → machine limits → max accel X/Y to match. Raising only
one leaves you clamped.

## 3. Elegoo PLA filament

| Setting | Value | Notes |
|---|---|---|
| Nozzle | 200–215 °C (first +5) | Envelope for Elegoo PLA. Quality runs cooler (~200–205), Speed hotter (~210–215); pick the final value with the temp tower (Cal §5). |
| Bed | 60 first / 55–60 rest | bang-bang, fine for PLA |
| Flow ratio | ~0.98 | set from flow test (Cal §3) |
| Pressure advance | OFF (untick **Enable pressure advance**) if using Marlin K | Orca's PA checkbox **injects `M900 K` into start G-code and overrides firmware K every print** — so to rely on firmware K you must untick it. If instead you tune PA in Orca, that's fine (Orca's `M900` wins); keeping firmware `ADVANCE_K 0` avoids confusion. |
| Max volumetric speed | ~11 mm³/s (starting default) | Verify with Orca → Calibration → **Max volumetric speed** test (this guide §6). Not a per-hotend measured value yet. |
| Cooling | 0% layer 1 → 100% by layer 3 | PLA loves cooling |

## 4. Speed vs Quality

| Setting | ⚡ Speed | ◆ Quality |
|---|---|---|
| Layer height | 0.28 | 0.12–0.16 |
| First layer | 0.28 (or 0.24 if adhesion is marginal) | 0.20 |
| Line width | 0.45–0.50 | 0.40 |
| Walls | 2 | 3–4 |
| Top/bottom | 3/3 | 5/4 |
| Infill | 10–15% grid | 15–20% gyroid |
| Outer wall speed | 120–150 | 30–40 |
| Inner wall speed | 200–250 | 60 |
| Infill speed | 250–300 | 80 |
| Travel | 250 | 180 |
| Print accel | 1500–2000 (needs firmware) | 500 |
| Nozzle temp | 210–215 | 200–205 |
| Retraction | 0.8 mm @ 25 mm/s* | 0.6–0.8 mm @ 25 mm/s* |
| Overhang slowdown | off | on |
| Use for | drafts, jigs, big parts | minis, fits, display |

> \* **Retraction speed is capped at 25 mm/s** by the firmware E max feedrate (`DEFAULT_MAX_FEEDRATE`
> E = 25). Higher slicer values are silently clamped — tune retraction *distance*, not speed, or raise
> the E ceiling (`M203 E50` + `M500`) first.

Full per-profile notes: [`profiles/SPEED.md`](profiles/SPEED.md),
[`profiles/QUALITY.md`](profiles/QUALITY.md), [`profiles/printer-settings.md`](profiles/printer-settings.md).

## 5. Start / end G-code

See `index.html` §5. **Prerequisite (do this first):** `M420 S1 Z10` loads a **stored** mesh — but
with no stored mesh it silently prints with **zero compensation** (Marlin's "No mesh" warning only goes
to serial, which you can't see), risking a bad or crashing first layer. Run `macros/BUILD_MESH.gcode`
(Cal §9 — does `G29`+`M500`+enable) **once before ever using this start block**, or keep `G29` in the
start G-code until a mesh exists.

## 6. Orca calibration order

Temperature tower → Flow rate → Pressure advance (or Marlin K) → Retraction test → **Max volumetric
speed** (run Orca's Max Volumetric Speed test — there is no separate Calibration-guide MVS step; the
~11 mm³/s default in §3 is a starting point, verify it here). Each maps to a step in the
[Calibration Guide](../Calibration_Guide/GUIDE.md).

## Sources

- Orca Slicer calibration docs: <https://github.com/SoftFever/OrcaSlicer/wiki/Calibration>
- Ellis' Print Tuning Guide: <https://ellis3dp.com/Print-Tuning-Guide/>
- Elegoo PLA spec sheet (temp ranges): Elegoo product/filament documentation

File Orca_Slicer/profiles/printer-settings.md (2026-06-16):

# Orca printer settings — Hoverfly (enter once)

Custom **Marlin** printer. These mirror the firmware so Orca never commands more than the board allows.

## Machine
- Bed shape: **210 × 210 mm** (rectangular). Firmware caps travel at 210 (`X/Y_BED_SIZE`). The plate
  is physically 220×220 — bump firmware *and* this together if you want the extra ring.
- Max print height: **250 mm**.
- Nozzle diameter: **0.4 mm**. Origin front-left (0,0). G-code flavor: Marlin. Extruder: **direct drive**.

## Motion ability (match firmware)
- Max speed: X 500, Y 500, Z 5, E 25 (mm/s)
- Max acceleration: X 500, Y 500, Z 100, E 5000 (mm/s²) — raise X/Y to 1500–2000 after Calibration §7 (this is the Orca machine limit; you must *also* raise the firmware ceiling in Cal §7 — both, firmware first)
- Max jerk: leave default (X/Y have no effect — Marlin ignores `M205` jerk under Junction Deviation 0.08, classic jerk off)

## Retraction (direct drive — Sprite Pro)
- Length: **0.8 mm** (range 0.6–1.0). Speed: **25 mm/s**. Z-hop: 0.2 mm (optional).
- **Speed ceiling:** the firmware E max feedrate is 25 mm/s, so any higher retraction speed is silently
  clamped. Set 25 here (or raise `DEFAULT_MAX_FEEDRATE` E / `M203 E50` if you want faster). Tune *distance*.
- Do **not** use Bowden-sized retraction (>2 mm) — it will grind/heat-creep on a direct drive.

## Start G-code (loads stored mesh, no re-probe)
```gcode
M104 S[nozzle_temperature_initial_layer]
M140 S[bed_temperature_initial_layer]
G28
M420 S1 Z10                               ; requires a stored mesh — run BUILD_MESH.gcode (Cal §9) once first, or replace with G29
M190 S[bed_temperature_initial_layer]
M109 S[nozzle_temperature_initial_layer]
G92 E0
G1 Z2.0 F3000
G1 X2 Y20 Z0.3 F5000
G1 X2 Y200 E15 F1500
G92 E0
```

## End G-code
```gcode
M104 S0
M140 S0
G91
G1 E-2 F2700
G1 Z10 F600
G90
G1 X5 Y200 F3000
M84
```

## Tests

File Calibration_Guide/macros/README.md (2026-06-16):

# SD-card macro files (no-terminal calibration)

Hoverfly has **no G-code terminal** (no Raspberry Pi / OctoPrint / USB console), so the calibration
steps that need a one-off command are packaged here as small `.gcode` files you **print from the SD
card**. Marlin runs them like any print.

## How to use

1. **Copy these `.gcode` files to the root of your printer's SD card** (once).
2. When a step in [`../GUIDE.md`](../GUIDE.md) / [`../index.html`](../index.html) says
   *"Run `NAME.gcode` from SD"*, on the printer select **Print → `NAME.gcode`**.
3. Files whose name starts with `SET_` **must be edited first** — open them in a text editor, change the
   value on the marked line (`<-- EDIT`), save, recopy to SD.

## What each file does

| File | Purpose | Edit first? | Verify on LCD |
|---|---|:---:|---|
| `PID_HOTEND.gcode` | Hotend PID autotune @205 °C, saves result | no | no numeric readout — confirm by a stable temp hold |
| `PID_BED.gcode` | Bed PID autotune (only if you compiled `PIDTEMPBED`) | no | no numeric readout — confirm by a stable bed temp hold |
| `ESTEPS_TEST.gcode` | Extrude exactly 100 mm to verify E-steps | no | — (measure the filament) |
| `SET_ESTEPS.gcode` | Set & save extruder steps/mm | **yes** | Configuration → Advanced Settings → Steps/mm → E steps/mm |
| `SET_PA.gcode` | Set & save Linear Advance K | **yes** | no stock LCD readout for K — verify by print result |
| `SET_ACCEL.gcode` | Set & save acceleration limits | **yes** | Configuration → Advanced Settings → Acceleration |
| `SET_SHAPER.gcode` | Set & save Input Shaping freqs (only if IS compiled) | **yes** | only if `SHAPING_MENU` compiled (it's off) — else verify by ringing-tower result |
| `SET_ZOFFSET.gcode` | Set & save probe Z-offset | **yes** | Configuration → Probe Z Offset |
| `SET_ZCURRENT.gcode` | Set & save Z TMC2209 run current (mA) | **yes** | no stock LCD readout — confirm by Z torque / no skips |
| `BUILD_MESH.gcode` | Heat, home, probe mesh, save, enable | no | Configuration → (Bed) Leveling → Mesh viewer |

## Good to know

- **`M303` (PID) pauses at the end** and waits for you to acknowledge on the LCD — that's normal.
- **`M500` (save to EEPROM)** is built into each macro that changes a stored value. You can also save
  any time from the LCD: **Configuration → Store Settings**.
- **`M500` here writes flash-emulated EEPROM** (the SKR Mini E3 V2.0 has no real EEPROM — it uses a
  reserved flash sector). Reliable day-to-day, but **a reflash can change the EEPROM layout and reset
  stored values to defaults** — re-verify (and re-save) PID, E-steps, Z-offset, K, accel, and rebuild
  the mesh after any firmware update.
- **Many things don't need a macro at all:**
  - **LCD menu** handles steps/mm, acceleration/feedrate/jerk, babystep Z + store, and the mesh viewer.
  - **Orca Slicer's Calibration menu** generates the temperature / flow / pressure-advance / retraction /
    max-volumetric-speed tests as ordinary prints — no codes needed.
- **Serial-only commands can't show output here.** `M48` (probe repeatability), `M503` (settings dump),
  and `M420 V` (mesh print-out) only report over USB serial, which you don't have. Use the **LCD mesh
  viewer** instead of `M420 V`, and **defer `M48`** until the planned Klipper move (its Mainsail/Fluidd
  web console gives you a full terminal). See the firmware review's *Future: Klipper* section.

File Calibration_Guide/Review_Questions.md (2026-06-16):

# Calibration Guide — Review Questions & Notes

My read-through of [`GUIDE.md`](GUIDE.md) / [`index.html`](index.html) (and the `macros/` + `STL/`
they reference) before I sit down to actually run the 9 steps. I checked the macros against the steps;
mostly they line up well. Questions below are real ambiguities or ordering issues I hit.

## Ordering / dependency questions

1. **Step 4 (zoffset) depends on Step 9 (bed-mesh) — forward reference.** Step 4's Setup says "mesh
   exists (or run Step 9 first time)." So on a *fresh* printer I apparently need to build the mesh
   (Step 9) before I can set Z-offset (Step 4), but the numbering puts mesh last. What's the actual
   first-run order? My guess: Step 1 (tram) → Step 9 (build a first mesh) → Step 4 (zoffset) → then the
   rest. If so, can the guide say that explicitly for the first pass, since the linear 1→9 order is
   self-contradictory here?

2. **The live Z-offset method in Step 4 won't persist until the firmware reflash.** Step 4's **Run**
   leads with the LCD live-babystep method ("dial by feel → Store Settings"). But babysteps only save
   into the probe offset if `BABYSTEP_ZPROBE_OFFSET` is enabled — which is currently **off** and needs a
   reflash (firmware review §3). The macro note and the "If fail" both mention this, but the **Run**
   line still puts the live method first. As written, a first-time reader will dial it in by feel, hit
   Store Settings, and **lose it on reboot**. Until I do that reflash, should I just use
   `SET_ZOFFSET.gcode` with a measured number? I'd promote that caveat to the top of the step.

3. **PID (Step 2) is tuned at 205 °C, but the temp tower (Step 5) might pick 200.** I autotune the
   hotend at 205 in Step 2, then three steps later possibly settle on 200 or 210 from the tower. Do I
   need to re-run `PID_HOTEND.gcode` at my final chosen temp? The macro header says "re-run at your
   most-used print temperature" — so I think yes, but the step order doesn't loop back. Should Step 5
   (or "Done/save order") explicitly say "if your chosen temp differs from 205 by more than ~10°, re-run
   Step 2"? Minor, but it's the kind of thing I'd forget.

## How-do-I-know-it-worked questions (no terminal)

4. **Confirming a macro actually applied, with no console.** After I print e.g. `SET_ESTEPS.gcode` or
   `BUILD_MESH.gcode`, how do I verify the value took without `M503`? For E-steps I assume LCD →
   Steps/mm shows the stored value; for the mesh, the LCD mesh viewer. Can the guide list, per macro,
   "where on the LCD to look to confirm it saved"? That closes the loop for a no-terminal workflow.

5. **`M500` and the SKR Mini E3 V2.0's emulated EEPROM.** This board has no real EEPROM (it's flash-
   emulated). The macros all end in `M500` — confirming that's fully reliable here and survives reflash
   *except* when the EEPROM layout changes (which a firmware update can invalidate, silently resetting
   to defaults). Worth a note: after any reflash, re-verify stored values rather than assuming they
   carried over.

## Smaller questions

6. **Step 3 E-steps measurement precision.** Extruding 100 mm at 1 mm/s and measuring against a 120 mm
   mark with calipers/ruler — a 1 mm read error is a 1% e-step error. Is one run enough, or should I
   average two or three? Also: the macro heats to 205 and extrudes; it does **not** retract/cool the
   filament back, so I'll have a 100 mm string hanging — fine, just confirming that's expected and I
   snip it after.

7. **Step 8 (Input Shaping) is gated on a reflash that may fail to fit.** The step is clear that IS only
   runs "if compiled AND it fit on the F103," else it degrades to "lower acceleration." Just flagging
   for myself: don't spend time on the ringing-tower frequency sweep until I've confirmed the IS build
   doesn't overflow RAM (firmware review §7, and note the 20 KB / 48 KB discrepancy I raised there).

8. **Step 1 tramming with `M211 S0` (soft endstops off).** Disabling soft endstops to reach corners is
   fine, but is it re-enabled afterward? If the macro/LCD flow leaves `M211 S0` set, later moves could
   drive past limits. Confirm soft endstops get turned back on (or that this is LCD-jog only and `M211`
   is just reference).

## Notes to self

- Macros are well-built: `ESTEPS_TEST` and `BUILD_MESH` correctly heat before extruding/probing, PID
  macros run with the part fan on, and the `SET_*` files clearly say "EDIT FIRST." No complaints there.
- The "no terminal → Orca test / LCD menu / SD macro" framing is consistent across all three guides and
  the `CLAUDE.md` driver. I like that each step's **Run** line names the exact path.
- `CLAUDE.md` is set up to drive this interactively (read GUIDE, ask which `id` to start, one change at
  a time, log results). When I'm ready, I can run the session that way and have it append a `RESULTS.md`.
- Filament is Elegoo PLA (≈190–220 °C / 50–60 °C bed) — all temp/flow numbers assume that spool.
- The retraction 25 mm/s clamp is consistent with the other two guides. Good.
</content>

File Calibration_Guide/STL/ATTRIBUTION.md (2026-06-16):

# Calibration STL models — sources & licenses

## Generated for this repo (CC0 / public domain — do whatever you like)

Authored procedurally by [`_generate.py`](_generate.py) (in this folder). Re-run
`python3 _generate.py` to regenerate. Simple axis-aligned solids (box unions) that slice
cleanly on any slicer.

| File | Size | Purpose |
|---|---|---|
| `calibration_cube_20mm.stl` | 20×20×20 mm | XYZ dimensional-accuracy / steps & flow sanity check |
| `single_wall_flow_25mm.stl` | 25×25×20 mm | Single-wall flow / extrusion-multiplier test (slice: 1 perimeter, 0 top/bottom, 0% infill, or Spiral/Vase) |
| `firstlayer_patch_60mm.stl` | 60×60×0.30 mm | First-layer / Z-offset tuning patch |
| `bridge_test_40mm.stl` | 60×40×12 mm, 40 mm span | Bridging / part-cooling test |
| `temp_tower_70mm.stl` | 25×30×70 mm, 7 bands | Temperature tower — change nozzle temp per 10 mm band in the slicer (≈220 °C bottom → 190 °C top). Each band has a −Y overhang fin so temp-dependent overhang/bridging shows band to band. |
| `retraction_test_50mm.stl` | 48×8×50 mm, 32 mm gap | Two posts on a shared base; the nozzle travels across the gap each layer, so poor retraction leaves strings between them. |
| `ringing_tower_60mm.stl` | 20×15×61 mm | A column with a 5 mm nub every 10 mm; each nub forces a sharp direction change and the wall just after it echoes the machine's resonance (ghosting). For accel limits + Input Shaping. |

> The temp / retraction / ringing towers are **simplified procedural stand-ins** for the
> community "smart" towers listed at the bottom. They exercise the same physics but don't
> carry printed text labels or fancier features. Want the de-facto-standard versions?
> Download them and record their source + license in the last table.

## Downloaded community models

| File | Source | Author | License |
|---|---|---|---|
| `3DBenchy.stl` | <https://github.com/CreativeTools/3DBenchy> (`Single-part/3DBenchy.stl`, official repo) · <https://www.3dbenchy.com> | CreativeTools.se | **CC BY‑ND 4.0** — redistribute unmodified with attribution; **no derivatives** (don't reshape/remix the model). |

## Optional upgrades — fancier community models (not committed)

The de-facto-standard "smart" calibration prints, if you want richer features than the
generated towers above. Download into this folder and **record the exact source URL +
author + license here before printing/redistributing**:

| Model | Where | License |
|---|---|---|
| Smart temperature tower (PLA) | Printables #19094 / Thingiverse #2493504 | CC BY / CC BY-SA (check listing) |
| Retraction test tower | Thingiverse #2415908 and many mirrors | CC BY-SA |
| All-in-one calibration (CHEP) | Printables / Thingiverse | CC BY |
| Ringing / ghosting tower | Marlin docs / Printables | CC BY |

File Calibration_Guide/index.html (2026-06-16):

# Hoverfly — Calibration & Tuning Guide

A repeatable, ordered tune-up for the Ender 3 Pro · SKR Mini E3 V2.0 · Sprite Extruder Pro (direct drive) · CRTouch · Elegoo PLA

How to use this guide. Work the steps in order — each assumes the previous passed. Print the linked STL, compare your result to the reference diagrams and pass criteria, then adjust and re-test. Want a guided session? Open this folder with Claude — see CLAUDE.md — and it'll walk you through step by step. The same procedure in plain-text/machine-readable form is GUIDE.md.

Note: the diagrams below are schematic SVGs (the automated photo download was interrupted by a usage limit). Real reference photos can be added later.

Before you start

- Filament: Elegoo PLA — hotend ≈190–220 °C, bed ≈50–60 °C.
- Save any stored value with M500. M501 reloads, M502 resets to firmware defaults.
- Change one thing at a time, then re-test.
- Pair this with the firmware review and Orca guide.

No G-code terminal? Hoverfly has no Pi / OctoPrint / USB console, so each step's Run line says how to do it without one:

- LCD menu — steps/mm, acceleration, babystep Z, Store Settings (M500), mesh viewer.
- Orca → Calibration — generates the temperature / flow / pressure-advance / retraction tests as prints.
- SD macros in macros/ — copy to the SD card once, then "Print" the named file (SET_* files are edit-first).

The <pre> blocks show the raw M-codes for reference — you don't type them. M48 / M503 / M420 V are serial-only (use the LCD mesh viewer; defer M48 to the planned Klipper console).

First-run order (fresh printer): the steps are written 1→9, but Step 4 (Z-offset) needs an active mesh — a good first layer is mesh-compensated. On a brand-new printer run 1 → 2 → 3 → 9 (build first mesh) → 4 → 5–8. PID and E-steps (Steps 2–3) are independent and can precede the mesh; the mesh itself (Step 9) builds fine before Z-offset is dialed (it's relative). After that initial pass the numeric 1→9 order is fine for re-tuning.

## The 9 steps

1 · Bed tramming (mechanical level) 2 · Hotend PID autotune 3 · E-steps & flow 4 · Z-offset & first layer 5 · Temperature tower 6 · Retraction & pressure/linear advance 7 · Speed & acceleration 8 · Ringing & input shaping 9 · Bed mesh (ABL) & validation

## 1 · Bed tramming (mechanical level)

No STLLive moves

Goal: get all four corners within ~0.1 mm mechanically, so the CRTouch mesh only has to correct small variation — not a skewed bed.

Do it: heat the bed to 60 °C (it changes shape when hot), home, drop the nozzle to ~0.2 mm, and use the paper-drag test at each corner knob and the center.

M140 S60      ; heat bed
G28           ; home
G1 Z0.2 F600  ; nozzle near bed; jog to each corner and adjust knobs
; M211 S0    ; (reference only — disables soft endstops; re-enable with M211 S1 after)

The supported flow here is LCD jog only — no macro sends M211, so soft endstops stay on. If you ever disable them manually (M211 S0), re-enable with M211 S1 afterward (they also reset on power-cycle).

Good: equal paper drag at every corner + center.

Bad: drag tight on one corner, loose on the opposite — re-level.

Pass: corner-to-corner nozzle height varies < 0.1 mm. If fail: adjust knobs; if a corner can't reach, check springs and that both Z leadscrews sit at equal height (power off, hand-turn to match).

## 2 · Hotend PID autotune

No STLSD macro

Goal: hold the hotend within ±0.5 °C. Tune with the part fan in its printing state.

Run: Print macros/PID_HOTEND.gcode from SD — it autotunes with the fan on, applies, and saves. M303 pauses for an LCD acknowledge at the end. The stored constants are generic stock values, so a fresh autotune for the Sprite block is worthwhile.

M106 S255            ; part fan on (print-like cooling)
M303 E0 S205 C8 U1   ; autotune hotend @205C, 8 cycles, apply
M107                 ; fan off
M500                 ; save

Pass: steady temperature, no sawtooth > ±1 °C, no runaway trip. If fail: re-run with C10; check hotend fan and thermistor/heater seating. Existing values (21.73 / 1.54 / 76.55) are a fine fallback.

## 3 · E-steps & flow

single_wall_flow_25mm.stl

E-steps are already 423 (calibrated for the Sprite). Verify, then dial slicer flow.

Run: E-steps — Print macros/ESTEPS_TEST.gcode, measure, then set via the LCD Steps/mm menu or macros/SET_ESTEPS.gcode (edit first). Flow — use Orca's Flow Rate calibration.

### 3a · Verify E-steps

M83 ; G1 E100 F60     ; heat to 205C first; mark 120mm above extruder, extrude 100mm
; if actual ≠ 100mm:  M92 E<423 * 100 / actual>  then  M500

Measure the remaining filament 2–3 times (or re-run) and average — a 1 mm read error is ~1% of E-steps. Mark and measure against a fixed point on the extruder body, not the nozzle tip. The test extrudes 100 mm and does not retract, so expect a ~100 mm strand hanging from the nozzle — snip it off afterward. Confirm on LCD: Configuration → Advanced Settings → Steps/mm → E steps/mm.

### 3b · Flow / extrusion multiplier

Slice the flow cube with 1 perimeter, 0 top/bottom, 0% infill (or Vase mode), 0.2 mm layer. Measure the wall with calipers.

Good: wall = target line width, consistent, no gaps.

Bad: thin or split wall → raise flow; blobby/over-thick → lower flow.

Pass: wall within ±0.02–0.03 mm of target. If fail: new_flow = old_flow × target_wall / measured_wall (Orca → Filament → Flow ratio), reprint.

## 4 · Z-offset & first layer

firstlayer_patch_60mm.stl

Print the patch; adjust live with babystepping (double-click encoder → Babystep Z).

Run: Until you reflash with BABYSTEP_ZPROBE_OFFSET (firmware review §3), use macros/SET_ZOFFSET.gcode (edit M851 Z<value> + M500) — that persists. The LCD live-babystep method (double-click encoder → Babystep Z, dial by feel) is great for finding the value, but with BABYSTEP_ZPROBE_OFFSET off the babystep is not folded into the probe offset by Store Settings and is lost on reboot; once that flag is enabled, the live method persists with Configuration → Store Settings.

G28
M851 Z-3.49     ; current probe Z-offset (info)
; during layer 1: babystep DOWN if too high, UP if scraping
M500            ; save (persists Z only if BABYSTEP_ZPROBE_OFFSET is enabled — see firmware review §3)

Confirm on LCD: Configuration → Probe Z Offset.

Good: lines touch with no gaps, smooth uniform top.

Bad: visible gaps (nozzle too high) or translucent/scraped (too low).

Pass: solid patch, no gaps, no elephant-foot ooze, peels in one piece. If fail: adjust ±0.02–0.05 mm and reprint.

## 5 · Temperature tower

temp_tower_70mm.stlor a labeled tower — see ATTRIBUTION.md

Sweep ~220 → 190 °C (Orca's temperature-tower calibration inserts the per-band M104). Judge each band for adhesion, bridging, overhangs, and stringing.

Run: Orca → Calibration → Temperature tower generates the whole print — no codes.

Choose the lowest temp with strong layer bonding and clean surfaces — usually ~200–210 °C for Elegoo PLA.

Pass: a band that snaps strong with clean overhangs/minimal strings. If fail: all bands string → too hot / fix retraction (Step 6); all delaminate → too cold or over-cooled.

Loop back if needed: Step 2 autotuned PID at 205 °C. If your chosen tower temp differs from 205 by more than ~10 °C, re-run macros/PID_HOTEND.gcode after editing it to autotune at your final temp (M303 E0 S<temp>), then M500 — PID constants are mildly temperature-dependent, so tuning near your real print temp is best. A ±5–10 °C delta rarely matters.

## 6 · Retraction & pressure / linear advance

retraction_test_50mm.stlOrca PA test

Tune pressure advance first, then retraction — good PA relieves nozzle pressure and shrinks the retraction you need. Direct drive = short retraction: start ~0.6–0.8 mm, tune distance down until stringing returns, then back up one notch.

Run: Orca → Calibration → Pressure Advance (Pattern, Direct Drive) and Retraction test both generate prints. Apply PA via Orca, or macros/SET_PA.gcode; set retraction in Orca's filament/printer settings.

Retraction speed is capped at 25 mm/s — the firmware E max feedrate. Anything higher (the 35–45 mm/s you'll see quoted for Bowden) is silently clamped, so tune distance, not speed (or raise DEFAULT_MAX_FEEDRATE E first).

M83
; Orca Pressure Advance (Pattern, Direct Drive): sweep K 0.0–0.10 step 0.005,
; then a fine second pass at 0.002 around the best band. Or set Marlin K directly:
M900 K0.04     ; Linear Advance K — small values for Sprite direct drive
M500
; pick ONE: Orca PA or Marlin K, not both

Good: no strings spanning the towers; crisp corners.

Bad: webbing/strings → more retraction; corner bulge → adjust K.

Pass: no/wispy strings; corners crisp with no bulge and no gaps at perimeter starts. If fail: more retraction distance for strings (speed is capped at 25 mm/s; ≤~1.5 mm on direct drive); K up if corners bulge, down if they show gaps.

Note: Orca's Enable pressure advance checkbox injects M900 K into the print G-code and overrides firmware K every print, so untick it when you're relying on SET_PA.gcode/M500 (Marlin K).

## 7 · Speed & acceleration

calibration_cube_20mm.stl

Raise acceleration in steps and watch for ghosting and skipped steps. Firmware default print accel is a conservative 500; the light Sprite can usually go higher.

Run: set accel via the LCD Acceleration menu or macros/SET_ACCEL.gcode (edit values first), then print the cube from SD to test.

M201 X1000 Y1000   ; raise max accel to test
M204 P1000         ; print accel
M500               ; save only the values you settle on

Confirm on LCD: Configuration → Advanced Settings → Acceleration.

Pass: 20 mm cube measures 20 ±0.2 mm on each axis; no layer shift; acceptable ringing. If fail: back off accel; if dimensions are consistently off, check belt tension and steps/mm (X/Y 80, Z 400).

## 8 · Ringing & input shaping

ringing_tower_60mm.stl

Ghosting (echoes after sharp corners) comes from frame resonance. A ringing tower's oscillation spacing encodes the frequency.

Run: only if Input Shaping is compiled and fits. Sweep with the slicer after-layer macro (below), then apply with macros/SET_SHAPER.gcode (edit the measured frequencies first).

Ghost echoes after a corner. Their period → resonant frequency for the shaper.

First confirm it fits the F103. Enable INPUT_SHAPING_X/Y + SHAPING_MIN_FREQ 20.0 (bounds the SRAM step buffer), build, and check the linker doesn't say "region RAM overflowed" before printing. Then print the tower at high accel (M204 S1500) sweeping frequency per layer:

; slicer "after layer change" G-code — sweeps M593 F 15→60 Hz up the tower:
M593 F{(layer_num < 2 ? 0 : 15 + 45.0 * (layer_num - 2) / 297)}

; read the smoothest band, convert height→Hz, then set per axis:
M593 X F40 ; M593 Y F38             ; frequencies (YOUR measured values)
M593 X D0.15 ; M593 Y D0.15         ; damping (zeta) — refine in 0.05 steps
M500

Then re-tune Linear Advance K (Step 6) after Input Shaping — the sweep runs with LA off, so K is finalized last. If the firmware won't build/flash with IS at all, instead lower acceleration (Step 7) to the ring-free value. First-class resonance compensation is part of the planned Klipper migration.

## 9 · Bed mesh (ABL) & validation

firstlayer_patch_60mm.stl

Probe the bilinear mesh at print temperature, store it, and validate the first layer everywhere.

Run: Print macros/BUILD_MESH.gcode from SD (heats, homes, probes, saves, enables). View the result on the LCD mesh viewer — M420 V and M48 are serial-only, so skip M48 probe-repeatability until the Klipper console.

Probe at real print temp. PREHEAT_BEFORE_LEVELING is on, but LEVELING_BED_TEMP is currently set to 50 (Configuration.h:1936) — below your ~60 °C PLA bed, so the mesh is probed ~10 °C cold. An aluminum bed warps differently when hot, so a mesh probed cold misses warp that's present while printing. Set #define LEVELING_BED_TEMP 60 (reflash), or probe fresh in start G-code after the bed soaks: M190 S60 → G4 S300 (soak) → G28 → G29 → M500.

Confirm on LCD: Configuration → (Bed) Leveling → Mesh viewer.

M140 S60 ; M104 S150   ; bed to print temp; warm nozzle (low ooze)
M190 S60 ; M109 S150    ; wait for both
G28
G29                    ; probe bilinear mesh
M500                   ; store
M420 S1 Z10            ; enable leveling + fade height (put M420 S1 in your slicer start G-code)
; optional, separately: G26 B60 H205  (if G26_MESH_VALIDATION compiled) prints a mesh-check pattern

Pass: mesh Z range < ~0.3–0.4 mm (view on the LCD mesh viewer); first layer equally good center and edges. If fail: redo Step 1 (tramming); consider 5×5 grid and a smaller PROBING_MARGIN (firmware review §5–6).

Save order when done: PID saved → flow set in Orca → Z-offset saved → best temp + retraction + K saved → accel set → mesh stored and M420 S1 in slicer start G-code. Each macro saves with M500; or use the LCD → Store Settings after an LCD change.

Flash-emulated EEPROM caveat (SKR Mini E3 V2.0): there's no real EEPROM — M500 writes to a reserved flash sector and is reliable day-to-day, but a reflash can change the EEPROM layout and reset all stored values to defaults. After any firmware update, re-verify (and re-save) PID, E-steps, Z-offset, K, accel, and rebuild the mesh — don't assume they survived.

Hoverfly calibration guide · diagrams are schematic SVG (photos pending) · GUIDE.md · CLAUDE.md · firmware review · Orca guide · README · GitHub (https://github.com/samuelkordik/Hoverfly)

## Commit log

2026-06-08 Initialize README with project details
    Added project description and specifications for the Hoverfly 3D printer.
2026-06-08 Document Marlin configuration adjustments in README
    Added detailed Marlin configuration adjustments for the Ender-3 Pro with specific settings for PID tuning, probing, and bed leveling.
2026-06-15 Update Firmware pointer for Sprite Extruder Pro calibration; document changes
    Point the Firmware submodule at the sprite-extruder-calibration branch
    (E steps 93->423, EDITABLE_STEPS_PER_UNIT, FAN1 freed for hotend auto-fan)
    and add a "Changes Since Last Documented" section to README.md capturing
    the delta.
2026-06-16 Add Hoverfly documentation set (firmware review, Orca + calibration guides)
    Generated by a multi-agent research workflow, then finished and verified by hand:
    - docs/firmware-review/ — prioritized Marlin config review (HTML + markdown).
    Surfaces the dual-Z discrepancy, untuned Linear Advance, the S-curve x
    Linear Advance incompatibility, Input Shaping feasibility on the STM32F103,
    and the 25 mm/s E-feedrate retraction clamp.
    - Orca_Slicer/ — Orca setup for Elegoo PLA with Speed + Quality profiles
    (HTML + markdown + profiles/).
    - Calibration_Guide/ — 9-step ordered tune-up (HTML), a machine-parseable
    GUIDE.md, a CLAUDE.md interactive driver, and STL test models: cube, flow,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
    [bridge_test_40mm.stl, cal-pid.json, calibration_cube_20mm.stl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]
2026-06-16 Correct dual-Z wiring, document fan setup, rework calibration for no-terminal use
    Confirms the dual-Z motors are parallel-wired via the Creality kit's stock
    splitter (not series, as previously assumed), and documents the new dual
    24V 5015 blower parts-cooling setup. Reworks the calibration guide and
    CLAUDE.md to run entirely without a G-code terminal — via LCD menu, Orca
    calibration tests, or new SD macro files in Calibration_Guide/macros/ —
    and adds a concise Klipper-migration note for the future.
2026-06-16 Apply 25 expert review edits to Hoverfly guides (FW-Q1–Q9, CAL-Q1–Q8, ORCA-Q1–Q8).
    Corrected misconceptions and clarified processes:
    - S-curve + Linear Advance coexist fine on Marlin 2.1.2.7 (downgrade from HIGH to LOW priority)
    - LEVELING_BED_TEMP = 50 confirmed; offer both firmware fix (60) and no-terminal workaround
    - Probe margin 25 verified-safe: auto-clamps grid to stay on bed, no trial-and-error needed
    - Z current stock value = 580 mA; added SET_ZCURRENT.gcode macro for live tuning (UART mode)
    - BABYSTEP_ZPROBE_OFFSET off → babysteps not persisted; reordered Step 4 setup to lead with SET_ZOFFSET.gcode
    - First-run order: 1→2→3→9→4→5–8 (mesh must exist before Z-offse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
2026-06-16 Add Review_Questions.md files as reference documentation from expert review.
    These artifacts track the questions and findings from the 25-item expert review
    that was applied to firmware, calibration, and Orca Slicer guides.
